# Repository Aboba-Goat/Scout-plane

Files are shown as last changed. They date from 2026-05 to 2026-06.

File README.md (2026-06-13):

# Scout-plane
Planes are cool, watching a plane fly makes you reminisce on how far technology has brought human kind. But do you know what is even cooler? Watching a plane that's watching you! (and everything else around) from 20-30 m up in the air.
That's why me and a friend created a practical cheap stable efficient and modular RC plane never before seen (That can record).

Scout Plane Zine page

#

# Highlights:
Top of the line modularity that is stable and quick to assemble/dissasemble.

Camera that records and sends the videos to your phone mid-flight.

Durable design.

Power efficient and (Cool looking), did I mention it can be assembled easily ?

d3

# What makes it modular ?
After you cut out the fuselage/wings following the 3D design,and you assembled the motors/servo's. Glue the horizontal sticks like in the picture and connect the vertical sticks that will act as rettention pins holding the whole plane together and giving you free access with minimal effort
d2

# PCB Schematics for the flight controller
Screenshot 2026-05-17 at 23 01 41 (1)

# PCB Schematics for the plane electronics
Screenshot 2026-05-17 at 23 06 21 (1)

# How To Build:
Step 1 — Cut Out All the Foam Parts

Cut each piece carefully from your polystyrene board using a hobby knife. Follow the dimensions below exactly.

Nose (front of fuselage)
 Cut a strip that tapers from 32 cm on one end down to 7.5 cm on the other, and is 8 cm wide. Fold it into the nose shape.
 
Middle fuselage
 Cut a strip 34 cm long × 9 cm wide. Fold into shape.
 
Rear fuselage
 Cut a strip 34 cm long, tapering from 21.5 cm wide on one end to 11 cm wide on the other. Fold into shape.
Wings (make 2 identical pieces)

 Cut a strip 24 cm long × 16 cm wide. Shape it into an airfoil profile (curved top, flat bottom) matching the 3D model.
Then, measured 2.5 cm from one end, cut out a slot 10 cm long × 2 cm wide — this is your aileron. Fold the aileron so it's 0.4 cm tall in the middle when bent. Repeat for the second wing.

Elevator
 Cut a strip 11.5 cm long × 9 cm wide and shape into an airfoil. Then cut one side at a 5° angle so that edge measures 11 cm total. The angled side will be glued to the fuselage later.
 
Horizontal stabilizer
 Cut a strip 27 cm long × 3 cm wide and fold into its final shape.
 
Vertical stabilizer + rudder
 Cut a strip 17 cm long, tapering from 10 cm wide on one end to 8 cm wide on the other. Shape it into a cone.
On one side of the cone, make a 15° indent into the foam. Make sure there's 3.5 cm clearance between the bottom and top of the cone. Then, 1 cm from the top, cut out a slot 6 cm long × 2 cm wide — this is your rudder.

Retention pin tubes
 Cut hollow tube sticks to these lengths:
3 cm × 1
4 cm × 1
6 cm × 1
23 cm × 1
30 cm × 2
The 23 cm tube gets permanently glued to the back of the fuselage. The two 30 cm tubes should overlap by 1 cm in the middle when the plane is assembled — this is intentional so the retention pin locks both sections together.

Refer to the 3D model for exact tube placement positions.

Step 2 — Install the Electronics
Motor — Mount the brushless motor in the nose of the fuselage as shown in the 3D model. Connect it to the ESC.
Power chain — Connect the ESC to the BEC 5V module, then connect the BEC to the receiver.
Battery — Glue the battery in place and connect it to the receiver.
Camera — Mount the FPV camera and connect it to the receiver.
Servos — Install one servo per control surface (ailerons, elevator, rudder) in the positions shown in the 3D model. Connect each servo to the receiver.

Step 3 — Attach Control Surfaces
Hot glue the ailerons onto the wings and connect them to their servo horns with hinges.
Do the same for the elevator.
Hot glue the vertical stabilizer to the rear of the fuselage.
Important: Do NOT glue the fuselage sections together — except for the front (nose) and middle section. The remaining sections are meant to be held together with the retention pins so the plane can be disassembled.

Step 4 — Final Assembly
Slide all the fuselage sections together using the retention pins. Lock everything in place and you're done — your plane is ready to fly!

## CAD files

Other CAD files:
3D files/Full Plane.x_t

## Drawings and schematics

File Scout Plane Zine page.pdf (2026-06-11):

# SSccout⁻Planee

# Modular

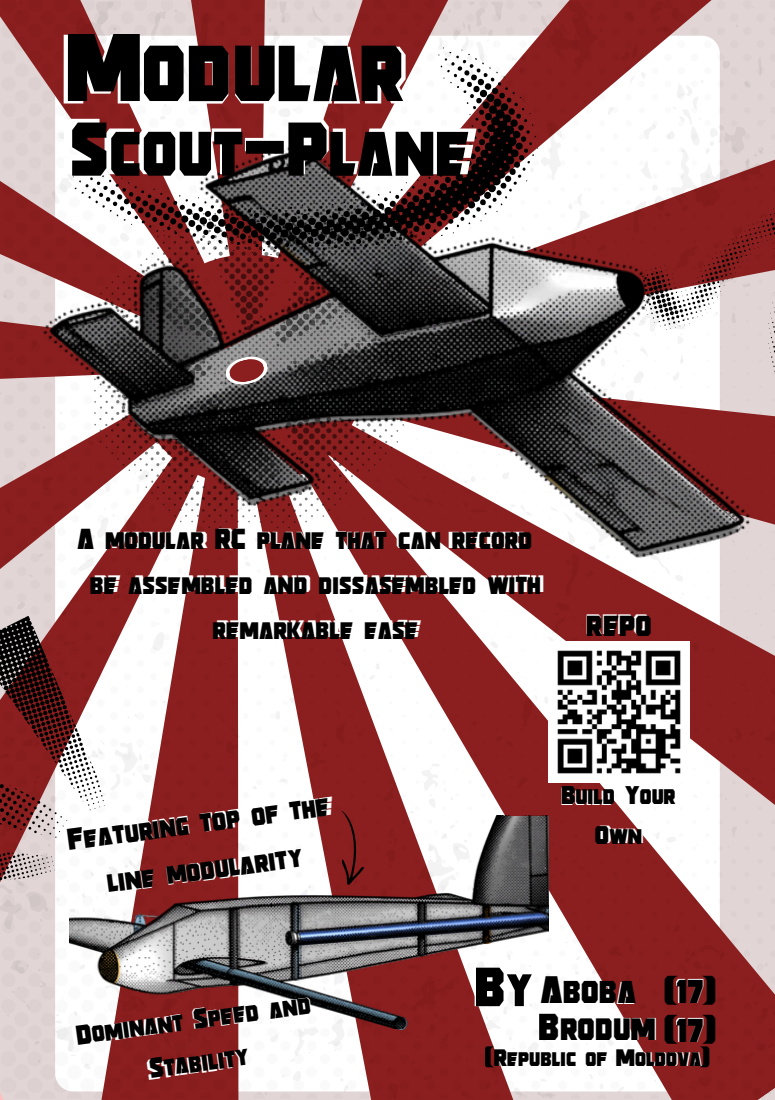
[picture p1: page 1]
Stability; modular; RC plane; that can record; assembled and; dissasembled with; be assembled and

remarkable ease | remarkable ease | | REPO Build Your Build Your Own Own

Featuring top of the line modularity

ByAboba (17) Brodum (RepublicofMoldova)

Dominant Speed and (17)

Dominant Speed and

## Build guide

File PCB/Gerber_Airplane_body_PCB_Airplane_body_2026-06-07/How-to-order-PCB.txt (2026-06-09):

How to Order PCB

Please refer to:
https://docs.easyeda.com/en/PCB/Order-PCB

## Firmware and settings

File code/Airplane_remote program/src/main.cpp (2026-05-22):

/*Note from the guy that made this code:
This code is for controlling an airplane remotly using the HC12 Module and the ili9341 320x240 display

P.S this code works and you can control the plane with it but the data i send to the plane needs to be calibrated. So, this code is not finished because of these inconveniences. But i really want to do this RC plane so i am gonna update my github afer i get some first hand expirience with the plane. 
                                                                pushsw
                                                              ____|____
                                                   leftsw    --|     | -- rightsw
 /----------------|--------------------------------------------|-----|----------\
|                                                    -----   -----   -----      |      
|                         /---------------------\   | (_) | | (_) | | (_) |     |                               
|                         |                     |    -----   -----   -----      |     
|                         |                     |     but1    but2   but3       |         
|                         |                     |                               | 
|      __________         |                     |        __________             |           
|      |   __   |         |                     |        |   __   |             |             
|      |  (  )  |         |         TFT         |        |  (  )  |             |                    
|      |  (__)  |         |                     |        |  (__)  |             |          
|      |________|         |                     |        |________|             |           
|       joystick1         |                     |         joystick2             |
|                         |                     |                               |
|                         |                     |                               |
|                         \---------------------/                               |                     
|                                                                               |
 \------------------------------------------------------------------------------/
joystick1 = controls the plane's roll 
joystick2 = controls the plane's pitch and yaw
buttons = extra controls for the plane 
leftsw and rightsw = controls the plane's speed
pushsw = extra control for the plane




*/
#include <Arduino.h>
#include <SPI.h>
#include <TFT_eSPI.h>
#include <SoftwareSerial.h>

#define DWIDTH 240
#define DHEIGHT 320
#define HC12 Serial2

// pin definitions 
#define RXHC12 17
#define TXHC12 18
#define but1 1
#define but2 2
#define but3 8
#define joystick1x 4
#define joystick1y 5
#define joystick2x 6
#define joystick2y 7
#define pushsw 12
#define rightsw 13
#define leftsw 14

TFT_eSPI tft = TFT_eSPI();
TFT_eSprite spr[2] = {TFT_eSprite(&tft), TFT_eSprite(&tft)};
uint16_t *sprPtr[2];
String dataRecived[10];

#define planelat dataRecived[0]
#define planelong dataRecived[1]
#define planespeed dataRecived[2]
#define planealt dataRecived[3]
#define planeroll dataRecived[4]
#define planebattery dataRecived[5]
#define planetemp dataRecived[6]

int planeSpeed = 0;
void recivingData();
void sendingData();
void setingup();
void setup()
{
  
  HC12.begin(9600, SERIAL_8N1, 17, 18);
  Serial.begin(115200);
  bool x = false;
  tft.init();
  tft.initDMA();
  tft.setRotation(2);
  tft.fillScreen(TFT_BLACK);
  sprPtr[0] = (uint16_t *)spr[0].createSprite(DWIDTH, DHEIGHT / 2);
  sprPtr[1] = (uint16_t *)spr[1].createSprite(DWIDTH, DHEIGHT / 2);
  spr[1].setViewport(0, -DHEIGHT / 2, DWIDTH, DHEIGHT);
  // spr[0].setTextDatum(MC_DATUM);
  // spr[1].setTextDatum(MC_DATUM);
  uint16_t calData[5] = {568, 2923, 441, 3263, 0};
  tft.setTouch(calData);
  tft.startWrite();
  /////////////////////////////////////////////////////////////////////////
  setingup();
}
void UI(float bang = 0, int alt = 0, String longg = "0.000", String lat = "0.000", int temp = 0, int battery = 0)
{
  // spr[0].fillSprite(TFT_WHITE);
  float speed = 23.5;
  float distance = 0;
  int batteryLevel = 0;
  float ang = bang * (3.14 / 180);
  float sinAng = sin(ang);
  int x = 70, y = 60, r = 50;
  int f = int(float(r) * sinAng);
  int x1 = int(float(r) - float(r) * cos(ang));
  /////////////////////////////////////////////////////////////////////
  spr[0].fillSprite(TFT_BLACK);
  spr[0].drawCircle(x, y, r, TFT_WHITE);
  spr[0].fillCircle(x, y, 4, TFT_GREEN);
  spr[0].drawLine(x + 4, y - 2, x + r - 7, y - 2, TFT_WHITE);
  spr[0].drawLine(x + 4, y + 2, x + r - 7, y + 2, TFT_WHITE);
  spr[0].drawLine(x - 4, y - 2, x - r + 7, y - 2, TFT_WHITE);
  spr[0].drawLine(x - 4, y + 2, x - r + 7, y + 2, TFT_WHITE);
  spr[0].drawPixel(x + 3, y + 3, TFT_WHITE);
  spr[0].drawPixel(x - 3, y - 3, TFT_WHITE);
  spr[0].drawPixel(x - 3, y + 3, TFT_WHITE);
  spr[0].drawPixel(x + 3, y - 3, TFT_WHITE);
  spr[0].drawFastHLine(x - 2, y - 4, 5, TFT_WHITE);
  spr[0].drawFastHLine(x - 2, y + 4, 5, TFT_WHITE);
  /////////////////////////////////////////////////////////////////////
  spr[0].drawLine((x - r) + x1, y - f, (x + r) - x1, y + f, TFT_GREEN);
  spr[0].drawLine((x - r) + x1, y + 1 - f, (x + r) - x1, y + 1 + f, TFT_GREEN);
  spr[0].drawLine((x - r) + x1, y - 1 - f, (x + r) - x1, y - 1 + f, TFT_GREEN);
  /////////////////////////////////////////////////////////////////////
  spr[0].fillCircle(x, y, 2, TFT_BLACK);
  spr[0].setTextColor(tft.color565(53, 181, 141));
  spr[0].drawCentreString(String(int(bang)) + " deg", x, y - 30, 1);
  // spr[0].drawFastVLine(180, 20,100,TFT_WHITE);
  //////////////////////////////////////////////////////////////////////
  spr[0].drawFastVLine(x + r + 70, y - 50, 100, TFT_WHITE);
  spr[0].setTextColor(TFT_WHITE);
  for (int i = 0; i < 10; i++)
  {
    spr[0].drawFastHLine(x + r + 67, y + 50 - (i * 11), 7, TFT_WHITE);
    spr[0].drawNumber(i * 15, x + r + 74, y + 50 - (i * 11) - 3, 1);
  }
  spr[0].drawCentreString("m", 220, 0, 2);
  spr[0].drawCentreString(String(alt), x + r + 50, y + 50 - (alt * 11 / 15) - 3, 1);
  spr[0].drawFastHLine(x + r + 57, y + 50 - (alt * 11 / 15), 8, TFT_GREEN);
  /////////////////////////////////////////////////////////////////////
  spr[1].fillSprite(TFT_BLACK);
  int x2 = 10, y2 = 120, r2 = 57;
  spr[1].drawCentreString("Plane up for:", 120, y2 + r2 + 5, 2);
  spr[1].drawCentreString("20:33", 120, y2 + r2 + 25, 7);
  spr[1].setTextColor(TFT_GREEN);
  spr[1].drawCentreString("Connected", 120, y2 + r2 + 95, 4);
  spr[1].setTextColor(TFT_WHITE);
  for (int i = 0; i < 2; i++)
  {
    spr[i].drawRect(x2, y2, 130, r2, TFT_WHITE);
    spr[i].drawString("Long:" + longg + " deg", x2 + 5, y2 + 5, 1);
    spr[i].drawString("Lat:" + lat + " deg", x2 + 5, y2 + 15, 1);
    spr[i].drawString("Temperature:" + String(temp) + " C", x2 + 5, y2 + 25, 1);
    spr[i].drawString("Distance(FSP): " + String(distance), x2 + 5, y2 + 35, 1);
    spr[i].drawString("Battery: " + String(batteryLevel) + "%", x2 + 5, y2 + 45, 1);
    spr[i].drawString("Speed km/h:", x2 + 135, y2, 2);
    spr[i].drawCentreString(String(speed), x2 + 175, y2 + 25, 4);
    tft.pushImageDMA(0, i * DHEIGHT / 2, DWIDTH, DHEIGHT / 2, sprPtr[i]);
  }
}
long long unsigned int t1 = millis();
int fps = 0;
void loop()
{
  UI(planeroll.toFloat(), planealt.toInt(), planelong, planelat, planetemp.toInt(), planebattery.toInt());
  uint16_t x = 0, y = 0;
  bool pressed = tft.getTouch(&x, &y);
  if (pressed)
  {
    tft.fillCircle(x, y, 10, TFT_RED);
    Serial.printf("Touch at %d,%d\n", x, y);
  }
  recivingData();
  if(digitalRead(leftsw) == 0 && millis()-t1 > 50){
    planeSpeed--;
    t1 = millis();
  }
  else if (digitalRead(rightsw) == 0 && millis()-t1 > 50){
    planeSpeed++;
    t1 = millis();
  }

  // fps++;
  // if(millis() - t1 > 1000){
  //   Serial.println("FPS: " + String(fps));
  //   fps = 0;
  //   t1 = millis();
  // }
}
void setingup()
{

  for (int i = 0; i < 2; i++)
  {
    spr[i].fillSprite(TFT_BLACK);
    spr[i].setTextColor(TFT_RED);
    spr[i].drawCentreString("Not Connected", 120, 120, 4);
    spr[i].drawCentreString("Waiting for Plane...", 120, 150, 2);
    tft.pushImageDMA(0, i * DHEIGHT / 2, DWIDTH, DHEIGHT / 2, sprPtr[i]);
  }
  while (true)
  {
    if (Serial.available())
    {
      break;
    }
  }
  for (int i = 0; i < 2; i++)
  {
    spr[i].fillSprite(TFT_BLACK);
    spr[i].setTextColor(TFT_YELLOW);
    spr[i].drawCentreString("Setting starting coordinates...", 120, 120, 2);
    spr[i].drawCentreString("Long: ", 120, 150, 2);
    spr[i].drawCentreString("Lat: ", 120, 170, 2);
    tft.pushImageDMA(0, i * DHEIGHT / 2, DWIDTH, DHEIGHT / 2, sprPtr[i]);
    spr[i].setTextColor(TFT_WHITE);
  }
  delay(4000);
  while (true)
  {
    if (Serial.available())
    {
      break;
    }
  }
}
void sendingData()
{
  String data = "%";
  data += String(digitalRead(but1)) + "#";  // button1
  data += String(digitalRead(but2)) + "#";  // button2
  data += String(digitalRead(but3)) + "#";  // button3
  data += String(map(digitalRead(joystick1x),0,4095,0,180)) + "#";  // joystick1
  data += String(map(digitalRead(joystick1y),0,4095,0,180)) + "#";  // joystick1
  data += String(map(digitalRead(joystick2x),0,4095,0,180)) + "#";  // joystick2
  data += String(map(digitalRead(joystick2y),0,4095,0,180)) + "#";  // joystick2
  data += String(planeSpeed) + "&";  // speed
  HC12.println(data);
}
void recivingData()
{
  String data;
  if (HC12.available())
  {
    data = HC12.readStringUntil('\n');
    int index = 0;
    while (data[index] != '%')
    {
      index++;
    }
    index++; // Move past the '%'
    for (int i = 0; i < 7; i++)
    {
      dataRecived[i] = data.substring(index, data.indexOf('#', index));
      // Serial.println(dataRecived[i]);

      if (data.indexOf('#', index) > data.indexOf('&', index))
      {
        dataRecived[i] = dataRecived[i].substring(0, dataRecived[i].indexOf('&'));
        // Serial.println(dataRecived[i]);
        break;
      }
      index = data.indexOf('#', index) + 1;
      // data = data.substring(data.indexOf('&')+1);
    }
  }
}

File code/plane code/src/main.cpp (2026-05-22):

// created by brodum in may 2026
// this is the code for the plane 
#include <Arduino.h>
#include <ESP32Servo.h>
#include <TinyGPSPlus.h>
#include <SoftwareSerial.h>
#include <Adafruit_BMP085.h>
#include <Adafruit_MPU6050.h>
#include <Adafruit_Sensor.h>
#include <Wire.h>

Servo flapServoRight;
Servo flapServoLeft;
Servo backServoRight;
Servo backServoLeft;
Servo backServoUp;
//////////////////
Adafruit_BMP085 bmp;
//////////////////
Adafruit_MPU6050 mpu;
//////////////////
static const int RXPin = 1, TXPin = 2;
TinyGPSPlus gps;
SoftwareSerial ss(RXPin, TXPin);
//////////////////


#define HC12 Serial2
static const uint32_t GPSBaud = 4800;

void recivingData();
void sendingData();
void controlMovement(float speed, int angleRoll, int anglePitch, int angleYaw);

String dataRecived[10];
// button1 button2 button3 joystick1x joystick1y joystick2x joystick2y pushsw leftsw rightsw
#define but1 dataRecived[0]
#define but2 dataRecived[1]
#define but3 dataRecived[2]
#define joystick1x dataRecived[3]
#define joystick1y dataRecived[4]
#define joystick2x dataRecived[5]
#define joystick2y dataRecived[6]
#define planeSpeed dataRecived[7]
void setup() {

 Serial.begin(115200);
 HC12.begin(9600, SERIAL_8N1, 17, 18);
 ss.begin(GPSBaud);
 mpu.begin();
 bmp.begin();

 flapServoLeft.attach(7);
 flapServoRight.attach(5);
 backServoLeft.attach(10);
 backServoRight.attach(11);
 backServoUp.attach(12);
// make gyro start values constant so that they alaways face north(ill do it when i make the project)


 ledcAttach(4, 5000, 16);



}

void loop() {
  sendingData();
  recivingData();
  controlMovement(planeSpeed.toFloat(), joystick1x.toInt(), joystick2y.toInt(), joystick2x.toInt());
}


void sendingData()
{
  String data = "%";
  data += String(gps.location.lat()) + "#";  // 
  data += String(gps.location.lng()) + "#"; //
  data += String(gps.speed.kmph()) + "#"; //
  data += String(bmp.readAltitude()) + "#";//
  data += String(mpu.gyro.x()) + "#";//
  data += String(analogRead(13)) + "#";//
  data += String(bmp.readTemperature()) + "&";//
  // I could've also added gyroy and gyroz for calculating the speed on each vector but now I want to finnish this faster
  HC12.println(data);
}

void controlMovement(float speed, int angleRoll, int anglePitch, int angleYaw)
{
  //control for flaps
  switch(but2.toInt()){//flaps switch manual/automatic
    case 0:
    flapServoLeft.write(angleRoll);
    flapServoRight.write(180-angleRoll);
    break;
    case 1:
    flapServoLeft.write(90+mpu.gyro.x());
    flapServoRight.write(90-mpu.gyro.x());
    break;   
  }
  //control for backwings
    backServoLeft.write(anglePitch);
    backServoRight.write(anglePitch);
  //controls fo back up wing
    backServoUp.write(angleYaw);
  //motorpower
  switch(but1.toInt()){//motor power/ motor speed switch
    case 0:
      ledcWrite(4, map(speed, 0, 100, 0, 65535));
      break;
    case 1:
       if(speed < gps.speed.kmph()) ledcWrite(4, map(speed, 0, 100, 0, 65535)+map(gps.speed.kmph()-speed, 0, 100, 0, 65535));
       else if(speed > gps.speed.kmph()) ledcWrite(4, map(speed, 0, 100, 0, 65535)-map(speed-gps.speed.kmph(), 0, 100, 0, 65535));
       else if(speed == gps.speed.kmph()) ledcWrite(4, map(speed, 0, 100, 0, 65535));
       else ledcWrite(4, 0);
      break;
  }
}
void recivingData()
{
  String data;
  if (HC12.available())
  {
    data = HC12.readStringUntil('\n');
    int index = 0;
    while (data[index] != '%')
    {
      index++;
    }
    index++; // Move past the '%'
    for (int i = 0; i < 8; i++)
    {
      dataRecived[i] = data.substring(index, data.indexOf('#', index));
      // Serial.println(dataRecived[i]);
      if (data.indexOf('#', index) > data.indexOf('&', index))
      {
        dataRecived[i] = dataRecived[i].substring(0, dataRecived[i].indexOf('&'));
        // Serial.println(dataRecived[i]);
        break;
      }
      index = data.indexOf('#', index) + 1;
      // data = data.substring(data.indexOf('&')+1);
    }
  }
}

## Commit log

2026-06-09 Create PCB
2026-06-13 iam facut sa vada bomu dai accept
    [BOM.csv, BOM.tsv]
